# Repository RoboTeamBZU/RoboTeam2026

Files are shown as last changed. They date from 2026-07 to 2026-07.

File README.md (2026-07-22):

<div align="center">

# 🤖 RoboTeamBZU — WRO Future Engineers 2026

### Self-driving model car · LiDAR + Gyro + Encoder · Raspberry Pi 4

**Team:** RoboTeamBZU · Birzeit University · 🇵🇸 Palestine
**Members:** Bashar Ibrahim · Jinan Yousef · Basmala Assi

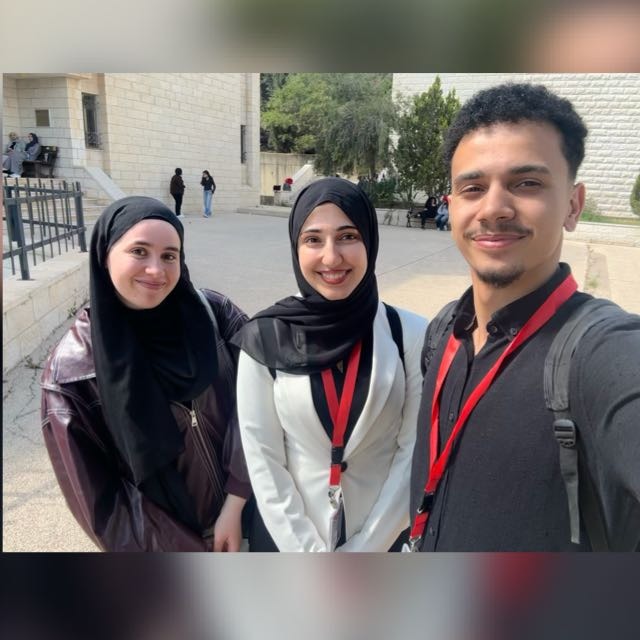
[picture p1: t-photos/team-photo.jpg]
RoboTeamBZU










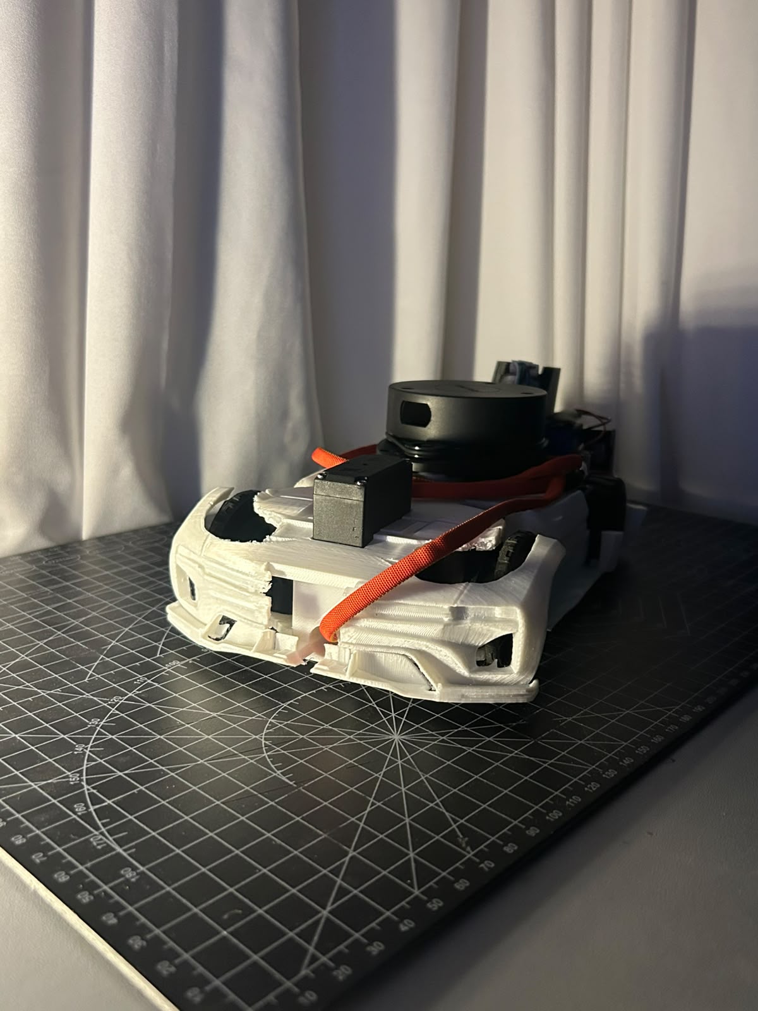
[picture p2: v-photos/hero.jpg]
RoboTeamBZU vehicle


</div>

---

## 🚗 What is this?

A small **autonomous car** that drives itself around the WRO Future Engineers track. It has **no remote control** — it senses the walls, keeps itself centered, turns at each corner, counts its laps, and stops on its own.

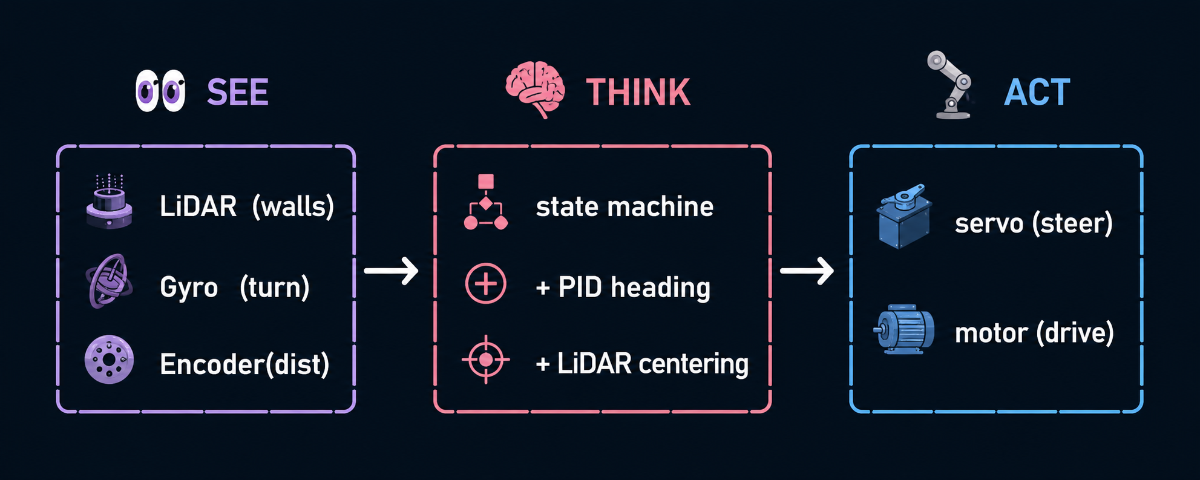
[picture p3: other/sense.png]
description


### 📸 The vehicle

| Front | Side | Top | Bottom |
|:---:|:---:|:---:|:---:|
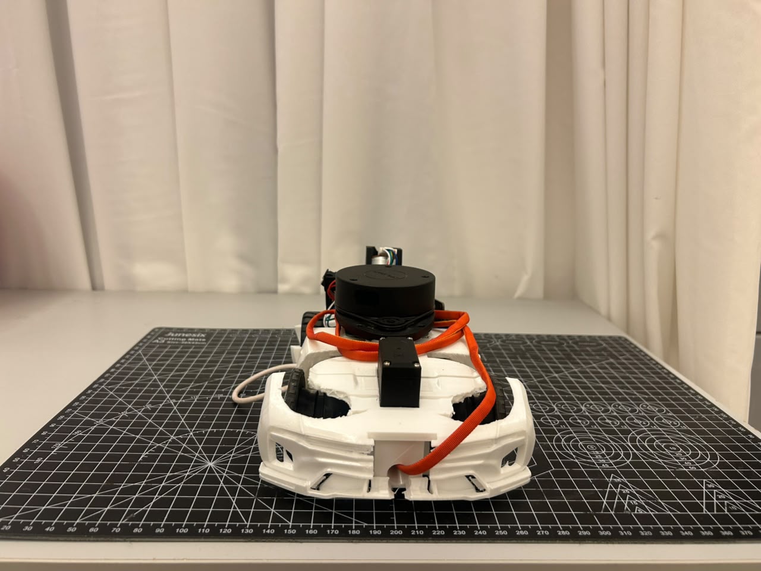
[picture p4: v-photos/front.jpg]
front
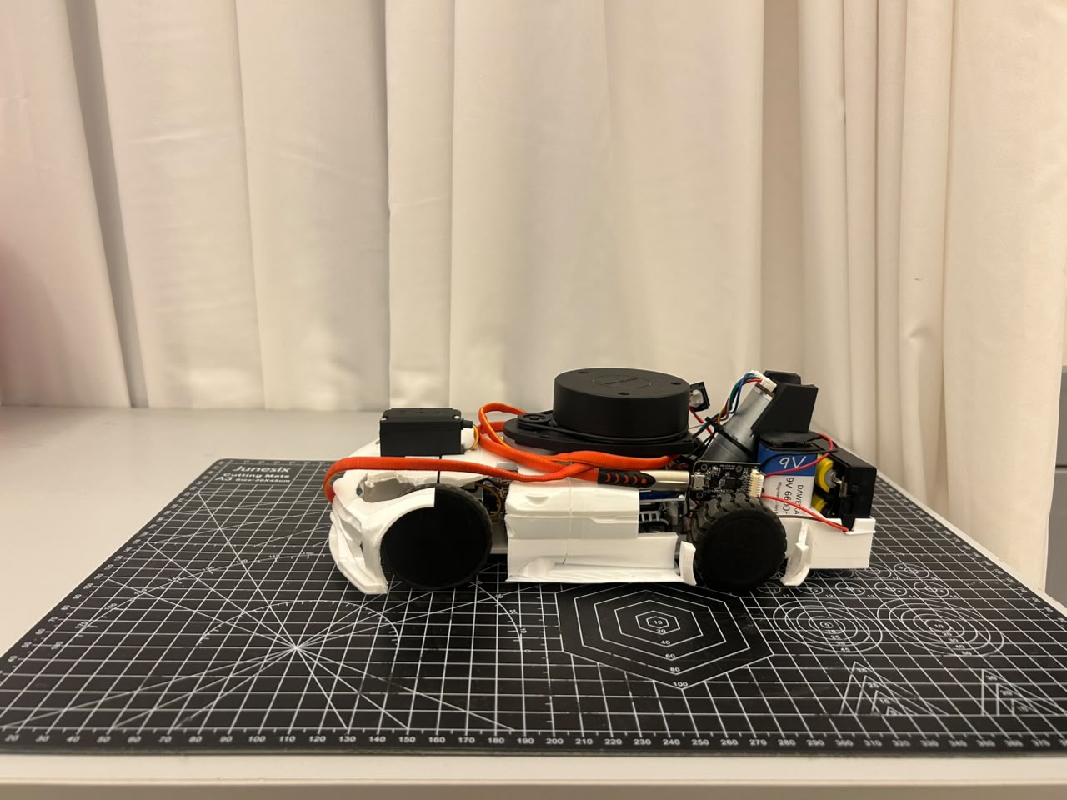
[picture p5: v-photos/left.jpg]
left
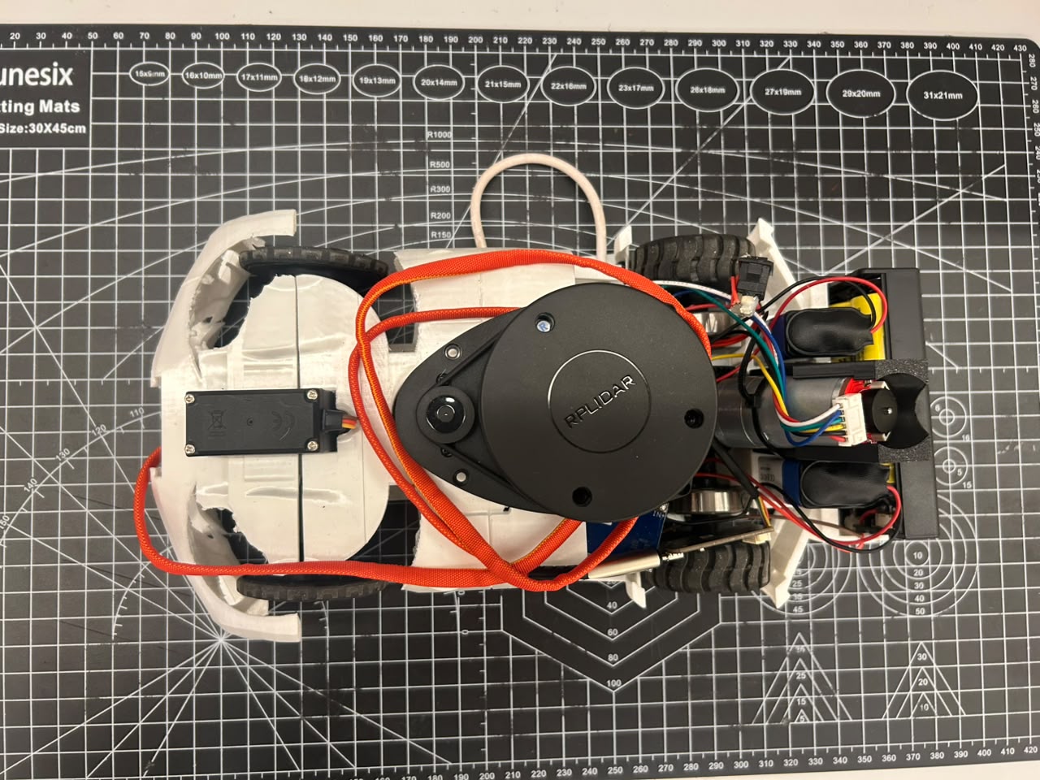
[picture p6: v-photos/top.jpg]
top
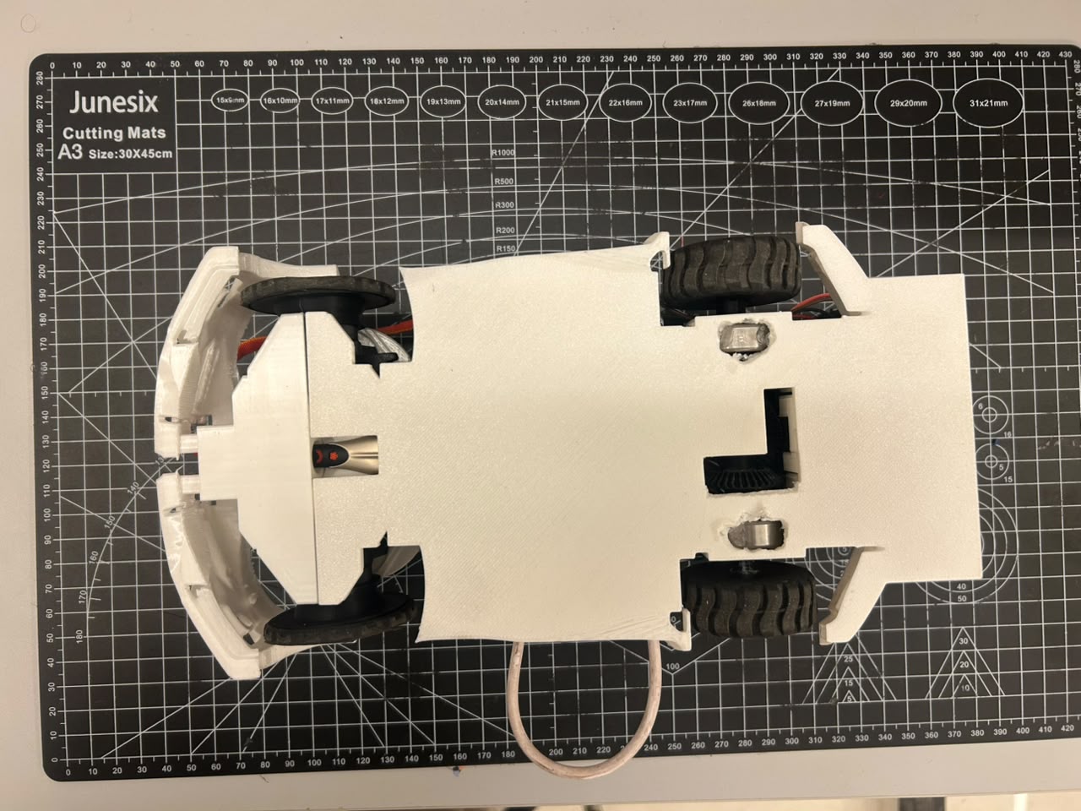
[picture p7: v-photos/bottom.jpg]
bottom
|  |  |  |  |

<sub>All six required angles are in [`/v-photos`](./v-photos).</sub>

---

## ⭐ Highlights

| | |
|---|---|
| 🧭 **Gyro-guided** | Heading held by a PID loop on the MPU6050 gyro |
| 📡 **LiDAR-centered** | RPLidar keeps the car in the middle of the lane and spots corners |
| 📏 **Dead reckoning** | Encoder + gyro track position with **no GPS** |
| 🔌 **Brownout-proof power** | 3 isolated battery sources + single star ground |
| 🖥️ **Live map** | Streams a real-time 2D/2.5D map + telemetry to a PC over Wi-Fi |
| 🔁 **Fully autonomous** | Drives with **zero** network — telemetry is optional |

---

## 🧩 How it works (30-second version)

```mermaid
flowchart LR
    L[📡 LiDAR] -->|front / left / right| C
    G[🧭 Gyro] -->|heading| C
    E[📏 Encoder] -->|distance| C
    C{🧠 State machine} -->|straight?| PID[PID + centering]
    C -->|corner?| TURN[90° turn profile]
    PID --> STEER[🦿 Servo]
    TURN --> STEER
    C --> MOTOR[⚙️ Drive motor]
    C -.optional.-> MAP[🖥️ PC live map]
```

1. **Go straight** — the gyro holds a fixed heading; the LiDAR nudges left/right to stay centered.
2. **See a wall ahead** (< 600 mm, confirmed 3×) — turn 90° toward the open side.
3. **Repeat** for **3 laps** (1080° total), then stop.
4. The turn direction (CW/CCW) is **auto-detected** at the first corner, because WRO randomizes it.

Full detail → [Software Architecture](./docs/Software-Architecture.md).

---

## 🛠️ The build at a glance

```
            ┌─────────────────────────────┐
   TOP DECK │  🍓 Pi 4   📡 LiDAR   🧭 IMU │   ← clear 360° LiDAR sweep
            └───────────────┬─────────────┘
                            │ 4× standoffs (rigid)
            ┌───────────────┴─────────────┐
   LOW DECK │ 🦿 servo   ⚙️ motor+encoder  │   ← heavy batteries kept low
            │        🔋🔋🔋 power          │
            └─────────────────────────────┘
             front (steered)      rear (driven)
```

| Subsystem | Choice | Why |
|---|---|---|
| **Drive** | 1× brushed DC motor, rear axle, DRV8833 | simple, car-like; kick-pulse launch fixes stall |
| **Steering** | servo + Ackermann, ±60° | predictable turn radius, decoupled from drive |
| **Heading** | MPU6050 gyro (Z axis) | smooth, high-rate, independent of walls |
| **Distance** | rotary encoder (205 counts/rev) | measured + tape-checked odometry |
| **Ranging** | RPLidar A1M8 | 360° walls; centering + corner detection |
| **Compute** | Raspberry Pi 4 | runs all flight code in Python |
| **Power** | 3 isolated sources, star ground | kills the brownouts a shared battery caused |

Deep dives → [Mechanical Design](./docs/Mechanical-Design.md) · [Power & Sensor Architecture](./docs/Power-and-Sensor-Architecture.md)

### 🔌 Wiring

| Schematic | Wiring diagram |
|:---:|:---:|
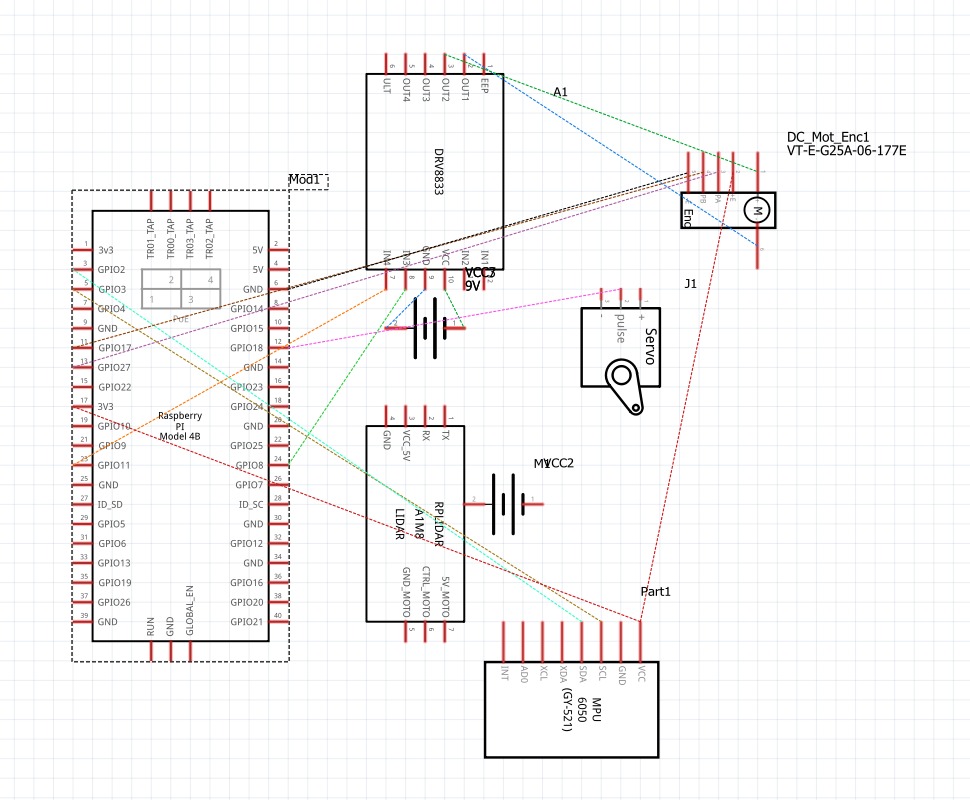
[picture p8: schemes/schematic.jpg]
schematic
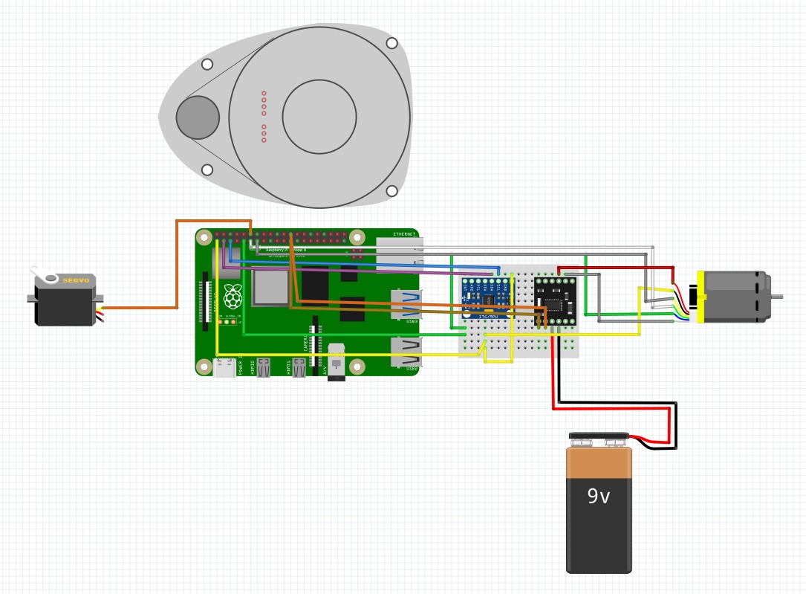
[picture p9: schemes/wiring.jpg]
wiring
|  |  |

<sub>Full pin map: [`other/pinout.md`](./other/pinout.md) · architecture notes: [`/schemes`](./schemes)</sub>

---

## 📂 Repository map

```
RoboTeam2026/
├── 📄 README.md                ← you are here
├── 📁 docs/                    ← the four engineering write-ups
│   ├── Mechanical-Design.md            (🔧 rubric 1)
│   ├── Power-and-Sensor-Architecture.md (⚡ rubric 2)
│   ├── Software-Architecture.md        (💻 rubric 3)
│   ├── Systems-Engineering.md          (🧠 rubric 4)
│   └── Build-and-Setup.md              (🛠️ how to reproduce)
├── 📁 src/                     ← all Python code
│   ├── wro_open.py             (Open Challenge autonomy)
│   ├── robot_mapper.py         (odometry + LiDAR mapping)
│   ├── map_viewer*.py          (PC live map / telemetry)
│   └── tests/                  (per-module bring-up scripts)
├── 📁 engineering-journal/     ← V1 → V2 → V3 → Final story
├── 📁 models/                  ← 3D-printable STL parts
├── 📁 schemes/                 ← wiring diagram
├── 📁 other/                   ← BOM, pinout, test procedure
├── 📁 v-photos/                ← 6 vehicle photos
├── 📁 t-photos/                ← team photos
└── 📁 video/                   ← performance video links
```

---

## 🚀 Quick start

**On the Raspberry Pi (autonomous run):**
```bash
sudo pigpiod                       # hardware-PWM daemon (jitter-free servo)
python3 src/wro_open.py            # Open Challenge — ENTER to arm, CTRL+C to stop
python3 src/grid_goto.py           # Obstacle Challenge — A* map navigation
```

**On a PC (optional live map — start this first):**
```bash
pip install numpy matplotlib pyvista
python3 src/map_viewer_pro.py      # telemetry HUD + 2.5D map
```

Full setup, dependencies, and troubleshooting → [Build & Setup](./docs/Build-and-Setup.md).

---

## 🎯 The two challenges

| Challenge | What the car must do | How | Status |
|---|---|---|---|
| 🟢 **Open Challenge** | 3 laps of a walled track, staying centered | reactive state machine: gyro PID + LiDAR centering | ✅ [`src/wro_open.py`](./src/wro_open.py) |
| 🟠 **Obstacle Challenge** | detect red/green signs, pass on the correct side, park | **live map + A\*** planner + camera color + "virtual walls" | ✅ [`src/grid_goto.py`](./src/grid_goto.py) |

**Two different brains for two problems.** The Open Challenge is *reactive* (follow the walls). The Obstacle Challenge is *deliberative*: the car builds a 50 mm occupancy grid, treats each traffic sign as a one-sided "virtual wall," and runs **A\* pathfinding** to a goal — re-planning several times a second as it discovers the track.

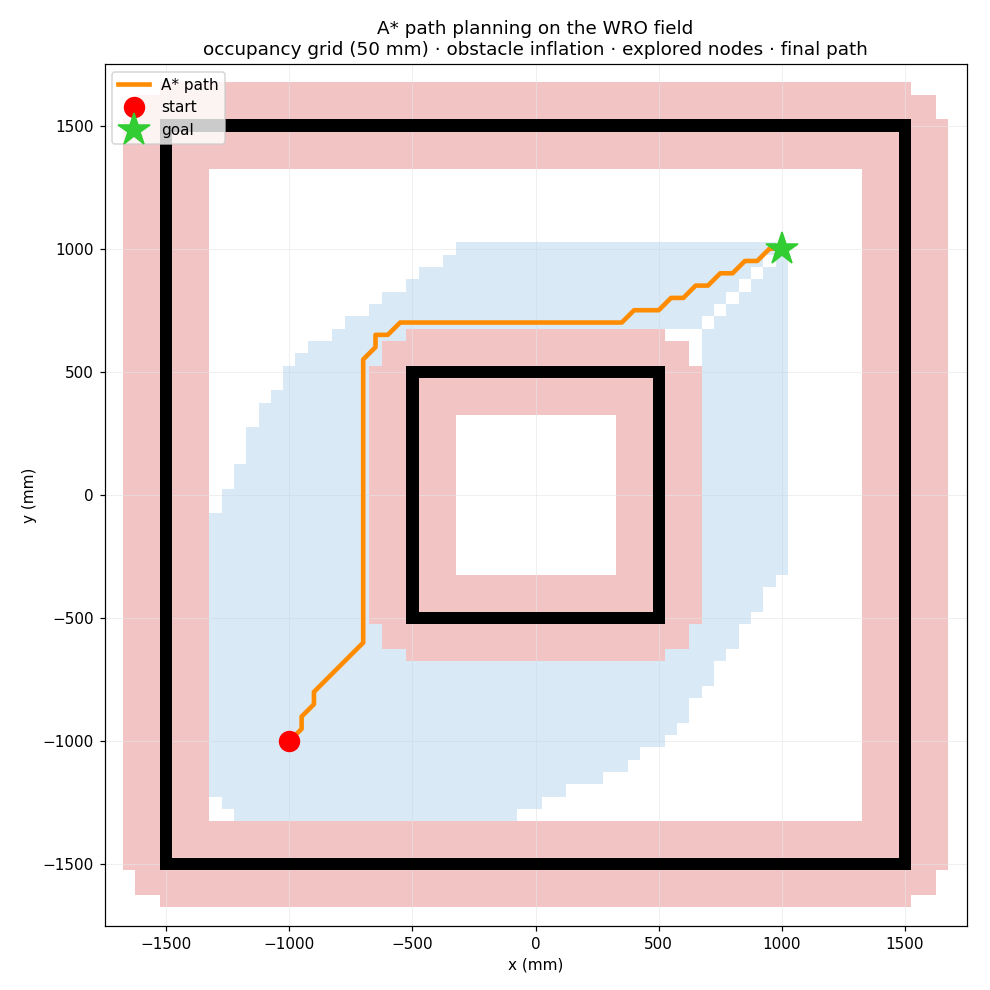
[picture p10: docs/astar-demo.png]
A* path planning on the WRO field


<sub>A\* routing the car around the inner wall — black = walls, pink = safety margin, blue = cells the search explored, orange = chosen path. Full write-up → [Software Architecture §6](./docs/Software-Architecture.md#6-obstacle-challenge-strategy--srcgrid_gotopy).</sub>

---

## 🧪 Engineering approach

We built the car in **four iterations**, each one a full *design → build → test → learn* loop:

```
V1 ──────► V2 ──────► V3 ──────► FINAL
baseline   clean       steady      repeatable
car        sensing     control     3-lap runs
```

- **V1** — car drives under gyro PID, but wanders and stalls.
- **V2** — LiDAR moved up + power split → clean scans, no brownouts.
- **V3** — hardware-PWM servo + kick pulse → no jitter, reliable launch.
- **Final** — start-line recalibration, centering smoothing, wind-up fix → consistent runs.

Read the full story → [Engineering Journal](./engineering-journal) · Trade-offs & risk analysis → [Systems Engineering](./docs/Systems-Engineering.md)

---

## 📚 Documentation index

| Doc | Covers | Rubric |
|---|---|---|
| [🔧 Mechanical Design](./docs/Mechanical-Design.md) | chassis, drive, steering, torque/speed | 1 |
| [⚡ Power & Sensor Architecture](./docs/Power-and-Sensor-Architecture.md) | power budget, wiring, sensors, calibration | 2 |
| [💻 Software Architecture](./docs/Software-Architecture.md) | state machine, PID, obstacle strategy | 3 |
| [🧠 Systems Engineering](./docs/Systems-Engineering.md) | interactions, trade-offs, iteration, risk | 4 |
| [🛠️ Build & Setup](./docs/Build-and-Setup.md) | reproduce & run the vehicle | 5 |
| [🧾 BOM](./other/BOM.md) · [🔌 Pinout](./other/pinout.md) · [✅ Test Procedure](./other/test-procedure.md) | parts, pins, validation | 5 |

---

<div align="center">

**RoboTeamBZU · Birzeit University · 🇵🇸 Palestine**
Bashar Ibrahim · Jinan Yousef · Basmala Assi

Built with 🍓 Raspberry Pi, 📡 LiDAR, and a lot of 🔁 iteration.

</div>

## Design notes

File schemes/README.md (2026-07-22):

Electromechanical diagrams
====

Diagram images in this folder (embedded in the main README):
- `schematic.jpg` — pin/connection schematic (Pi ↔ DRV8833, MPU6050, RPLidar, servo, encoder)
- `wiring.jpg` — Fritzing wiring diagram

schematic
wiring

Summary of the architecture:

**Power (three isolated sources, one star ground):**
- 9 V pack #1 → switch → DRV8833 VM (drive motor only)
- 9 V pack #2 → XL4015 buck (5.0 V) → steering servo VCC
- 2S Li-ion (7.4 V) → buck converter (5.1 V) → Raspberry Pi USB-C
- RPLidar A1M8: powered and read over a single USB connection to the Pi
- All grounds joined at one star point; the Pi connects to it with a single reference wire (Pin 9). Servo return current is routed to its own converter's ground, never through the Pi.

**Signal connections (Pi GPIO):**

| Pi pin | GPIO | Connects to |
|---|---|---|
| 1 | 3V3 | Encoder VCC, MPU6050 VCC |
| 3 | GPIO2 (SDA) | MPU6050 SDA |
| 5 | GPIO3 (SCL) | MPU6050 SCL |
| 9 | GND | Star ground (reference) |
| 11 | GPIO17 | Encoder A |
| 12 | GPIO18 | Servo signal (hardware PWM via pigpio) |
| 13 | GPIO27 | Encoder B |
| 16 | GPIO23 | DRV8833 IN1 |
| 18 | GPIO24 | DRV8833 IN2 |

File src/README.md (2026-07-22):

Control software
====

All code runs on the vehicle's Raspberry Pi 4 except the `map_viewer*` scripts, which run on a PC on the same Wi-Fi network and receive telemetry over UDP.

| File | Runs on | Purpose |
|---|---|---|
| `wro_open.py` | Pi | Open Challenge: state-machine navigation (gyro PID + LiDAR centering/corners) with built-in telemetry streaming |
| `grid_goto.py` | Pi | Obstacle Challenge: live 50 mm occupancy grid + A* planner + Pi-Camera sign detection + virtual-wall avoidance (streams to `grid_viewer.py`) |
| `robot_mapper.py` | Pi | Standalone odometry + LiDAR world-mapping streamer (mapping tests without driving logic) |
| `map_viewer.py` | PC | 2D top-down live map (matplotlib) |
| `map_viewer_3d.py` | PC | 2.5D live map (pyvista), walls extruded to real 100 mm height |
| `map_viewer_pro.py` | PC | 2.5D map + full telemetry HUD, chase camera, textured floor |
| `grid_viewer.py` | PC | Live occupancy-grid viewer for `grid_goto.py`: black cells, A* path/corridor, pillars, virtual walls, clickable coordinates |
| `sim/field_astar_demo.py` | PC | Offline A* illustration on a simulated WRO field (renders `docs/astar-demo.png`) |
| `tests/` | Pi | Component bring-up and calibration scripts, one per hardware module |

Dependencies (Pi): `adafruit-circuitpython-mpu6050`, `rplidar-roboticia`, `gpiozero`, pigpio built from source with `pigpiod` running. Obstacle Challenge (`grid_goto.py`) additionally uses `picamera2`, `opencv-python`, and `numpy` for the camera colour pipeline.
Dependencies (PC viewers): `numpy`, `matplotlib`, `pyvista`.

Calibrated constants used throughout: encoder 205 counts/rev (0.674 mm/count, 44 mm wheels); LiDAR direction windows remapped for a 180°-rotated mount; `GYRO_DIRECTION=-1`, `SERVO_DIRECTION=+1` (positive = left).

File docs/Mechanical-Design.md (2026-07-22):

# 🔧 Mechanical Design — Mobility & Chassis

> **Rubric criterion 1 — Mobility & Mechanical Design.** This document explains *what* the vehicle is built from, *why* each mechanical choice was made, and *how* those choices were validated through testing and iteration.

---

## 1. Overview

The vehicle is a **single-motor, front-steering (Ackermann-style) autonomous car** built on a rigid two-deck chassis. One brushed DC motor drives the rear axle; a servo steers the front wheels. This is the classic "car-like" layout the WRO Future Engineers rules assume, and it keeps the mechanics simple so engineering effort could go into sensing and control.

| Property | Value |
|---|---|
| Drive type | Rear-wheel drive, 1 × brushed DC motor |
| Steering | Front, servo-actuated Ackermann linkage |
| Wheel diameter | 44 mm |
| Track / wheelbase | See CAD in [`/models`](../models) |
| Turning basis | Gyro-closed-loop, ±60° servo range |
| Chassis | Two-deck (drivetrain below, electronics above) |
| Compute | Raspberry Pi 4 |

📷 Vehicle photos: [`/v-photos`](../v-photos) · CAD/STL: [`/models`](../models)

---

## 2. Chassis structure

```
        ┌─────────────────────────────┐   ← Upper deck: Pi, IMU, LiDAR,
        │   [Pi]  [LiDAR]   [IMU]      │     power distribution
        │                             │
        └───────────┬─────────────────┘
                    │ standoffs (4×)
        ┌───────────┴─────────────────┐   ← Lower deck: motor, driver,
   ┌──┐ │ [servo]        [motor+enc]  │ ┌──┐  battery packs, servo
   │  │ │      Ackermann     ▐▐       │ │  │
   └──┘ └─────────────────────────────┘ └──┘
   front                                 rear
 (steered)                            (driven)
```

**Why two decks?** Separating the drivetrain (lower) from the sensing/compute stack (upper) does three things:

1. **Keeps the LiDAR plane clear.** The RPLidar A1M8 needs an unobstructed 360° sweep. Mounting it on the top deck above the tallest components guarantees a clean scan of the field walls.
2. **Shortens and isolates wiring.** High-current motor wiring stays on the lower deck; low-level signal wiring (I²C, encoder, servo PWM) stays up top, reducing noise coupling.
3. **Lowers the center of mass** by keeping the heavy battery packs low, which improves stability during hard cornering.

The two decks are joined by four metal standoffs, giving a torsionally rigid frame — important because chassis flex would change the LiDAR-to-wall geometry mid-run and corrupt the wall-centering trim.

---

## 3. Drivetrain — motor & speed/torque reasoning

A single **brushed DC gearmotor** drives the rear axle through the wheels (44 mm diameter). Drive power comes from a dedicated 9 V pack through a **DRV8833** H-bridge driver.

### Speed vs. torque trade-off

The WRO field is a small arena; the vehicle needs **enough top speed to be competitive but enough low-end torque to launch cleanly from a standstill** and to hold speed through gyro-corrected steering corrections. Our reasoning:

| Requirement | Consequence for gearing |
|---|---|
| Fast, clean laps | Favor higher RPM |
| Reliable start from rest | Need standstill torque |
| Predictable control loop | Speed must be repeatable, not twitchy |

We run the motor at **80 % duty on straights** (`SPEED_STRAIGHT = 0.8`) and **55 % in turns** (`SPEED_TURN = 0.55`) — slowing for corners keeps the gyro turn profile repeatable and prevents understeer.

### The standstill-torque problem (and fix)

Early testing (see [engineering journal](../engineering-journal)) showed the motor could **stall at low duty when starting from rest** — not enough torque to overcome static friction. We solved it two ways:

1. **Mechanically** — reduced drivetrain friction and confirmed free-spinning wheels.
2. **In software** — a **kick pulse**: the driver briefly commands full power (`KICK_SPEED = 1.0` for `KICK_TIME = 0.15 s`) whenever the motor starts from rest, then drops to the commanded duty. This is retained as a safety margin. See `motor()` in [`src/wro_open.py`](../src/wro_open.py).

---

## 4. Steering — Ackermann servo linkage

The front wheels are steered by a single **servo** driving an Ackermann-style linkage. Key parameters (from [`src/wro_open.py`](../src/wro_open.py)):

| Parameter | Value | Meaning |
|---|---|---|
| `SERVO_MAX` | 60° | Mechanical steering limit |
| `SERVO_DIRECTION` | +1 | Positive command = steer **left** |
| `TURN_FULL_LOCK` | 55° | Angle held during a 90° corner |
| `TURN_RELEASE_DEG` | 25° | Ease off lock this close to target heading |

**Why a servo (not differential/skid steering)?** A steered front axle matches the car-like geometry of the challenge, produces a **predictable turn radius**, and lets us decouple *steering* from *drive* — the drive motor holds speed while the servo alone corrects heading. This makes the control problem far simpler than balancing two drive motors.

### Servo jitter fix
The servo jittered on software PWM. We moved it to the Pi's **hardware PWM via `pigpio`** (daemon `pigpiod`, built from source), which eliminated the jitter and gave a rock-steady steering signal. Documented in [`other/test-procedure.md`](../other/test-procedure.md).

---

## 5. Sensor mounting (mechanical)

| Sensor | Mount location | Mechanical reasoning |
|---|---|---|
| **RPLidar A1M8** | Top deck, highest point | Clear 360° sweep of walls; mounted **180° rotated** — compensated in software (`LIDAR_MOUNT_OFFSET = 180`) rather than re-machining the mount |
| **MPU6050 (IMU)** | Top deck, near center of rotation | Placing it close to the vehicle's yaw axis minimizes translational acceleration coupling into the gyro reading |
| **Rotary encoder** | On the drive axle | Direct odometry from wheel rotation; 205 counts/rev measured experimentally |

The LiDAR's 180° rotation is a good example of **choosing the cheaper fix**: instead of building a new bracket, we remapped the angle windows in code (front `170–190°`, left `80–100°`, right `260–280°`).

---

## 6. Design iterations that changed the mechanics

| Version | Mechanical change | Why |
|---|---|---|
| V1 | Baseline single-motor + servo chassis | Establish a working car-like platform |
| V2 | Raised & isolated LiDAR to top deck | Earlier low mount caught part of its own chassis in the sweep |
| V3 | Added kick-pulse-friendly drivetrain, hardware-PWM servo mount | Fix standstill stall + steering jitter |
| Final | Rigid two-deck standoff frame, IMU relocated near yaw axis | Reduce flex + cleaner heading signal |

Full narrative with photos: [engineering journal](../engineering-journal).

---

## 7. Reproducibility

- **CAD / STL** files: [`/models`](../models)
- **Vehicle photos** (all six angles required by WRO): [`/v-photos`](../v-photos)
- **Calibrated constants** (wheel diameter, counts/rev, servo range): [`other/pinout.md`](../other/pinout.md)
- **Bill of materials**: [`other/BOM.md`](../other/BOM.md)

Anyone with the CAD, the BOM, and the calibrated constants above can reproduce this chassis.

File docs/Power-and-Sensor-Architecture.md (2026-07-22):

# ⚡ Power & Sensor Architecture

> **Rubric criterion 2 — Power & Sensor Architecture.** This document covers the power system layout, the power budget, wiring, and every sensor: what it is, where it is placed, why, and how it is calibrated. The full wiring diagram lives in [`/schemes`](../schemes) and the exact pin map in [`other/pinout.md`](../other/pinout.md).

---

## 1. Design principle: three isolated sources, one star ground

The single most important power decision was to **split the vehicle onto three isolated power sources** and join them at a **single star ground**. Motors and servos create large, noisy current spikes; the Raspberry Pi and the I²C sensors are sensitive to voltage sag and ground bounce. Sharing one battery caused **brownouts and I²C errors** in early testing. Isolating the loads fixed it.

```
   ┌──────────────┐
   │ 9V pack #1   │──[switch]──► DRV8833 VM ──► DRIVE MOTOR
   └──────────────┘                              (noisy, high current)

   ┌──────────────┐
   │ 9V pack #2   │──► XL4015 buck (5.0V) ──► STEERING SERVO VCC
   └──────────────┘                              (spiky, inductive)

   ┌──────────────┐
   │ 2S 18650     │──► buck (5.1V) ──► USB-C ──► RASPBERRY PI 4
   │ Li-ion 7.4V  │                              (sensitive logic)
   └──────────────┘

   ┌──────────────┐
   │ RPLidar A1M8 │──── single USB cable (power + data) ──► Pi
   └──────────────┘

   ── ALL GROUNDS ──► ONE STAR POINT ──► single ref wire ──► Pi Pin 9
```

**Key rule:** the servo's return current is routed to *its own* converter ground, **never through the Pi**. This keeps servo current spikes out of the logic ground.

---

## 2. Power budget

| Rail | Source | Regulator | Feeds | Approx. draw |
|---|---|---|---|---|
| Motor VM | 9 V pack #1 | none (direct to DRV8833) | Drive motor | High, spiky (stall inrush) |
| Servo 5.0 V | 9 V pack #2 | XL4015 buck | Steering servo | Spiky under load |
| Pi 5.1 V | 2S 18650 (7.4 V) | buck → USB-C | Pi 4 + IMU + encoder | ~0.6–1.2 A continuous |
| LiDAR 5 V | Pi USB | (from Pi supply) | RPLidar A1M8 motor + sensor | ~0.3–0.5 A |
| 3.3 V logic | Pi onboard | Pi regulator | MPU6050, encoder | Low |

> ⚠️ **Why the Pi gets its own Li-ion pack:** the Pi + LiDAR is the largest *sustained* draw and the least tolerant of voltage sag. A dedicated 2S 18650 with a buck to 5.1 V keeps it above the brownout threshold even while the motor stalls.

---

## 3. Wiring / signal connections

Signal wiring from the Pi GPIO header (full table in [`other/pinout.md`](../other/pinout.md)):

| Pi pin | GPIO | Connects to |
|---|---|---|
| 1 | 3V3 | Encoder VCC, MPU6050 VCC |
| 3 | GPIO2 (SDA) | MPU6050 SDA |
| 5 | GPIO3 (SCL) | MPU6050 SCL |
| 9 | GND | **Star ground reference** |
| 11 | GPIO17 | Encoder A |
| 12 | GPIO18 | Servo signal (**hardware PWM** via pigpio) |
| 13 | GPIO27 | Encoder B |
| 16 | GPIO23 | DRV8833 IN1 |
| 18 | GPIO24 | DRV8833 IN2 |

Full Fritzing wiring diagram: [`/schemes`](../schemes).

---

## 4. Sensor suite

The vehicle localizes and navigates with three sensors. There is no GPS or external reference — everything is **onboard dead reckoning + LiDAR ranging**.

### 4.1 MPU6050 — IMU / gyro (heading)

| Property | Value |
|---|---|
| Interface | I²C (SDA GPIO2, SCL GPIO3) |
| Used axis | Z-axis gyro (yaw rate) |
| Placement | Top deck, near the vehicle's center of rotation |
| Role | Primary **heading** source — integrated to drive the steering PID |

**Placement reasoning:** mounting the IMU near the yaw axis minimizes translational acceleration bleeding into the gyro signal, giving a cleaner heading integral.

**Calibration & failure handling:**
- **Bias calibration at startup:** 300 samples of Z-gyro are averaged with the robot held still to compute `gyro_offset`, which is subtracted from every reading (`calibrate_gyro()`).
- **Thermal drift:** we measured ~1°/3 s drift traced to thermal bias. Mitigation: **re-calibrate at the start line after a 60 s warm-up**.
- **Deadzone:** small rates below `GYRO_DEADZONE` are zeroed so slow sensor noise doesn't accumulate into false heading, while real veers still register.

### 4.2 Rotary encoder — odometry (distance)

| Property | Value |
|---|---|
| Interface | Quadrature A/B (GPIO17, GPIO27) |
| Counts/rev | **205 (measured experimentally)** |
| Wheel diameter | 44 mm |
| Derived | `MM_PER_COUNT = π·44 / 205 ≈ 0.674 mm` |
| Direction | `ENCODER_DIRECTION = -1` |

**Calibration:** counts/rev were **measured**, not assumed, then **cross-checked** by pushing the robot exactly 500 mm along a tape measure and confirming the odometry read ~500 mm (`test_distance.py`).

### 4.3 RPLidar A1M8 — ranging (walls & corners)

| Property | Value |
|---|---|
| Interface | USB (`/dev/ttyUSB0` @ 115200), power + data on one cable |
| Placement | Highest point on the top deck (clear 360° sweep) |
| Mount orientation | **180° rotated** — compensated in software |
| Role | Wall-centering trim + front-wall corner trigger |

**Direction windows (robot frame, after the 180° remap):**

| Window | Angles | Used for |
|---|---|---|
| Front | 170–190° | Corner trigger (`front < 600 mm`) |
| Left | 80–100° | Centering + open-corridor detection |
| Right | 260–280° | Centering + open-corridor detection |
| Back | 350–360° / 0–10° | (available) |

**Calibration & failure handling:**
- Four-direction wall distances validated against a tape measure (`test_lidar_pi.py`).
- **Stale-stream bug fix:** a `stop()` + `reset()` is issued at startup after we discovered stale-descriptor errors on reconnect.
- Points with `quality == 0` or out of `MAX_DIST` (3000 mm) are discarded before use.

### 4.4 Raspberry Pi Camera — traffic-sign color (Obstacle Challenge)

| Property | Value |
|---|---|
| Part | 5 MP 175° fisheye CSI camera (OV5647, 1.7 mm lens) |
| Interface | CSI ribbon to the Pi |
| Placement | Front, facing forward, above the bumper |
| Role | Reads **red vs. green** traffic-sign pillars |
| Power | From the Pi (no separate rail) |

**How it's used:** LiDAR finds a pillar's *bearing*; the camera samples the HSV color at that bearing to decide the pass side. Red is matched with two hue ranges (hue wraps at 0/180°); a minimum pixel count rejects ambiguous frames. Details in [Software Architecture §6.3](./Software-Architecture.md#63-detecting-the-signs-sensor-fusion-lidar--camera). The Open Challenge does not use the camera.

---

## 5. Sensor fusion summary

```
 ENCODER ──(distance)──┐
                       ├──► DEAD-RECKONED POSE (x, y) ──► live map + odometry
 GYRO ─────(heading)───┘
                       └──► heading feeds STEERING PID (straights)
                                          + TURN profile (corners)

 LiDAR ──(front)──► corner trigger
       ──(left/right)──► wall-centering trim  +  turn-direction detection
```

Heading comes **only** from the gyro; distance comes **only** from the encoder; LiDAR never feeds the pose estimate directly — it corrects *where in the lane* the car sits and *when* to turn. This clean separation is what makes the failure modes easy to reason about (see [Systems Engineering](./Systems-Engineering.md)).

---

## 6. Reproducibility

- Wiring diagram: [`/schemes`](../schemes)
- Exact pinout + calibrated constants: [`other/pinout.md`](../other/pinout.md)
- Per-sensor bring-up scripts: [`src/tests/`](../src/tests)
- Component test log: [`other/test-procedure.md`](../other/test-procedure.md)
- Parts & sourcing: [`other/BOM.md`](../other/BOM.md)

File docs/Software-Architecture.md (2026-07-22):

# 💻 Software Architecture & Obstacle Strategy

> **Rubric criterion 3 — Software Architecture & Obstacle Strategy.** This document explains the code structure, the state machine, the control algorithms (PID, dead reckoning, LiDAR logic), how edge cases are handled, and how the software was tuned and validated. Source lives in [`/src`](../src).

---

## 1. Code map

All flight code runs on the **Raspberry Pi 4**; the `map_viewer*` scripts run on a **PC** on the same Wi-Fi and receive telemetry over UDP.

| File | Runs on | Purpose |
|---|---|---|
| [`src/wro_open.py`](../src/wro_open.py) | Pi | **Open Challenge** — state-machine navigation (gyro PID + LiDAR centering/corners) with telemetry streaming |
| [`src/grid_goto.py`](../src/grid_goto.py) | Pi | **Obstacle Challenge** — live occupancy grid + A\* planner + camera sign detection + virtual-wall avoidance |
| [`src/robot_mapper.py`](../src/robot_mapper.py) | Pi | Standalone odometry + LiDAR world-mapping streamer (mapping tests without driving logic) |
| [`src/map_viewer.py`](../src/map_viewer.py) | PC | 2D top-down live map (matplotlib) |
| [`src/map_viewer_3d.py`](../src/map_viewer_3d.py) | PC | 2.5D live map (pyvista), walls extruded to real 100 mm height |
| [`src/map_viewer_pro.py`](../src/map_viewer_pro.py) | PC | 2.5D map + full telemetry HUD, chase camera, textured floor |
| [`src/grid_viewer.py`](../src/grid_viewer.py) | PC | Live **occupancy-grid** viewer for the Obstacle Challenge: black cells, A\* path/corridor, pillars, virtual walls, robot arrow (click a cell to read its coordinates) |
| [`src/sim/field_astar_demo.py`](../src/sim/field_astar_demo.py) | PC | Offline A\* illustration on a simulated WRO field (generates the figure below) |
| [`src/tests/`](../src/tests) | Pi | Per-module bring-up & calibration scripts |

**Design philosophy:** small, single-responsibility modules. Sensing, pose estimation, control, and telemetry are separate functions so any one can be tested or retuned in isolation. That modularity is why each hardware module has its own test script (see [`other/test-procedure.md`](../other/test-procedure.md)).

---

## 2. The Open Challenge state machine

The Open Challenge is three laps of a walled track (no obstacles). The vehicle must stay centered, take corners, and stop after **3 laps = 1080° of cumulative heading**.

```mermaid
stateDiagram-v2
    [*] --> ARMED: press ENTER
    ARMED --> STRAIGHT: state zeroed, 1s corner-blind
    STRAIGHT --> STRAIGHT: gyro PID holds heading\nLiDAR trims to lane center
    STRAIGHT --> TURNING: front wall < 600mm\n(confirmed 3 scans)
    TURNING --> STRAIGHT: heading within 4° of target\n(+0.4s corner-blind)
    STRAIGHT --> FINISHED: |heading| >= 1080° - 15°
    FINISHED --> [*]: motor stop, servo center
```

| State | What it does |
|---|---|
| **ARMED** | On ENTER, all state is zeroed (heading, encoder, PID terms) and a 1 s "corner-blind" window prevents a false corner at the start line. |
| **STRAIGHT** | Gyro PID holds the snapped target heading (0/90/180/270…). LiDAR left/right distances trim the target to keep the car centered in the lane. Watches the front window for a corner. |
| **TURNING** | Full-lock steering toward `snapped + 90°·turn_dir`, easing off as it approaches. Drive slows to `SPEED_TURN`. |
| **FINISHED** | After 1080° cumulative heading, stop motor and center steering. |

**Turn direction is auto-detected** at the first corner (WRO randomizes CW/CCW): whichever side reads as the open corridor (`> 900 mm`) sets `turn_dir` for the whole run.

---

## 3. Control algorithms

### 3.1 Heading hold — PID on the straights
`pid_steer()` in [`wro_open.py`](../src/wro_open.py) runs a PID controller on heading error (`target − heading`):

| Gain | Value | Role |
|---|---|---|
| `KP` | 0.9 | Proportional — main corrective push |
| `KI` | 0.05 | Integral — removes steady drift (clamped ±30 to stop wind-up) |
| `KD` | 0.15 | Derivative — damps oscillation (low-pass filtered, `KD_FILTER = 0.3`) |

Integral is **reset when exiting a turn** so wind-up from the corner isn't carried into the next straight — a deliberate edge-case fix.

### 3.2 Lane centering — LiDAR trim
On straights, `smoothed_center_error(left, right)` averages the last 4 scans of `(left − right)`. Within a 30 mm deadzone the trim is zero; otherwise the target heading is nudged by up to ±6° (`CENTER_GAIN`, `CENTER_TRIM_MAX`) to steer back to the lane center. Smoothing prevents single noisy scans from jerking the wheel.

### 3.3 Corner detection & turn profile
- **Trigger:** front wall closer than `TURN_TRIGGER_DIST = 600 mm`, confirmed over `TURN_CONFIRM = 3` consecutive scans (debounce against a single bad reading).
- **Profile:** `turn_steer()` holds full lock (`55°`) until within `TURN_RELEASE_DEG = 25°` of the target, then ramps down linearly for a clean exit within `TURN_EXIT_TOL = 4°`.

### 3.4 Pose estimation — dead reckoning
`update_pose()` fuses **gyro (heading)** and **encoder (distance)** each loop:
```
heading += gyro_z * dt          # integrated yaw rate
x += Δdistance * cos(heading)   # advance along heading
y += Δdistance * sin(heading)
```
This pose drives the live map and telemetry. LiDAR points are transformed into world coordinates and streamed to the PC viewers.

---

## 4. Edge cases handled

| Edge case | Handling |
|---|---|
| False corner at start line | 1 s `START_BLIND` window after ARM |
| Double-trigger right after a turn | 0.4 s `POST_TURN_BLIND` window |
| Single noisy LiDAR scan | 3-scan confirm + 4-scan centering smoothing |
| PID wind-up through corners | integral clamped and reset on turn exit |
| Motor stall from rest | kick pulse (full power for 0.15 s) |
| Gyro thermal drift | warm-up + re-calibration at start line |
| LiDAR stale stream on reconnect | `stop()` + `reset()` at startup |
| Network hiccup | telemetry send wrapped in try/except; tracking continues |

---

## 5. Tuning & validation

Every module was validated in isolation before integration ([`other/test-procedure.md`](../other/test-procedure.md)):

1. **Servo** — sweep test; jitter fixed with hardware PWM.
2. **Gyro** (`test_gyro.py`) — verified 90°/360° physical rotations; measured drift.
3. **Motor** (`test_motor.py`) — direction + ramp; stall fix verified.
4. **Encoder** (`test_encoder.py`, `test_distance.py`) — 205 counts/rev, cross-checked at 500 mm.
5. **LiDAR** (`test_lidar_pi.py`) — four-direction distances vs. tape measure.
6. **Turning** (`test_turn.py`) — closed-loop turns to absolute headings.
7. **Mapping** — pushed-lap test: walls form closed straight lines and the trail returns to origin, validating dead reckoning **before** any autonomous run.

**Metric used to validate the map/odometry:** after a hand-pushed loop, the trail must return to the origin and walls must close into straight lines — a direct visual check that encoder + gyro drift is within tolerance.

---

## 6. Obstacle Challenge strategy — [`src/grid_goto.py`](../src/grid_goto.py)

The Obstacle Challenge replaces "follow the walls" with **"know where you are and plan a path."** Instead of a reactive state machine, the car builds a **live map** and runs an **A\* planner** to a goal cell, re-planning several times a second as the map fills in. Traffic signs (pillars) become geometry the planner must respect.

### 6.1 The big idea: occupancy grid + A\*
```mermaid
flowchart TD
    L[📡 LiDAR scan] --> G[50 mm occupancy grid\nfree / occupied / unknown]
    P[🧭 Gyro + 📏 Encoder] --> POSE[Pose x,y,h]
    POSE --> G
    CAM[📷 Pi Camera] --> PIL[Pillar color RED/GREEN]
    L --> PIL
    PIL --> VW[Virtual walls\non the forbidden side]
    G --> ASTAR{A* planner}
    VW --> ASTAR
    ASTAR --> WP[Waypoint follower\npure-pursuit steering]
    WP --> DRIVE[Servo + motor]
    ASTAR -.replan every 0.5s.-> ASTAR
```

- **The world is a grid of 50 mm cells** (`GRID_RESOLUTION_MM = 50`). The car starts at cell `(0,0)`, heading 0.
- Each LiDAR ray marks cells **free** along its length and **occupied** at its endpoint, using a confidence count (`OCC_CONFIRM = 3`) so one noisy scan can't create a phantom wall (`update_grid`, `occupied_cells`).
- **Unknown cells are treated as free** (optimistic planning): the car assumes open space and **re-plans every `REPLAN_S = 0.5 s`** as reality is revealed — this is what lets it start driving before it has seen the whole track.

#### How A\* finds the route

A* path planning on the WRO field

*The exact `astar()` from [`grid_goto.py`](../src/grid_goto.py), run offline on a simulated WRO field ([`src/sim/field_astar_demo.py`](../src/sim/field_astar_demo.py)). Black = real walls, pink = obstacle-inflation no-go zone, blue = cells A\* explored, orange = the final path.*

A\* is a best-first search that finds the **shortest collision-free path** from the robot's cell to the goal cell. For each candidate cell it keeps a score `f = g + h`:

- **`g`** — the real distance travelled from the start to that cell (straight moves cost `1.0`, diagonals `1.414`).
- **`h`** — a *heuristic* estimate of the distance still to go, here the straight-line (Euclidean) distance to the goal. Because `h` never over-estimates, A\* is guaranteed to return the shortest path.

It always expands the lowest-`f` cell next, which is why the blue "explored" region fans out *toward* the goal instead of searching everywhere — A\* is far cheaper than flooding the whole grid. Key implementation details in our version:

1. **Obstacle inflation** — every wall cell is grown by the robot's radius (`OBSTACLE_INFLATION_MM = 130 mm`, the pink band) so the *center* of the car can follow the path without a corner clipping a wall.
2. **Diagonal corner-cutting is blocked** — a diagonal move is only allowed if both orthogonal neighbours are free, so the path never squeezes through a wall's corner.
3. **Escape bubble** — the cells around the start are force-cleared so a car that starts hemmed against a wall can always plan its way out.
4. **Path simplification** — `simplify()` collapses the raw cell staircase into the fewest straight segments that stay collision-free, giving the smooth orange line the pure-pursuit follower actually drives.

In the figure the planner routes the car out of the bottom-left lane, **around the inner wall**, and into the top-right — exactly the reasoning it performs live, several times a second, as new walls and pillars appear.

### 6.2 Traffic signs → "virtual walls"
This is the core avoidance trick. A red pillar must be passed on one side, a green pillar on the other. Rather than special-casing steering, we turn each rule into **geometry the planner obeys** (`pillar_constraints`):

| Sign | Rule | What the code does |
|---|---|---|
| 🔴 **RED** | pass on the pillar's **right** | builds a **virtual wall** extending to the **left** of the approach line |
| 🟢 **GREEN** | pass on the pillar's **left** | builds a virtual wall extending to the **right** |

The virtual wall is a thin line of blocked cells on the forbidden side, plus an **L-shaped cap** forward from its tip so A\* can't sneak around the end through unknown-as-free space. The result: **A\* has exactly one legal way past each sign**, and steering falls out of the plan automatically. Passed pillars are culled (`_along(t) > -400`) so they never constrain the car again.

### 6.3 Detecting the signs (sensor fusion: LiDAR + camera)
1. **LiDAR finds candidates** (`find_pillars`): points inside a forward cone (`PILLAR_CONE_DEG = 40°`) are clustered; a cluster only counts as a pillar if it is **small** (`CLUSTER_MAX_SPAN ≤ 120 mm`) and **isolated** from the walls behind it (`isolated()` depth check). This rejects walls and corners.
2. **Camera reads the color** (`get_color`): the Pi Camera frame is converted to HSV and the region of interest **at the pillar's bearing** is sampled. Red uses two HSV ranges (the hue wraps at 0/180); the color with more pixels wins, above a `COLOR_MIN_PIXELS = 150` threshold. If no camera is present, a fallback alternates RED/GREEN for bench testing.
3. **Tracking** (`update_tracks`): detections are matched frame-to-frame in world coordinates and only promoted to a real pillar after `PILLAR_CONFIRM = 3` consistent hits — debouncing false positives before they ever affect the plan.

### 6.4 Following the plan
- **Pure-pursuit steering:** the follower aims at a **lookahead point** `LOOKAHEAD_MM = 210` along the path and steers with a proportional law (`HEAD_KP = 1.1`), interpolating between waypoints for a smooth line.
- **Closed-loop speed:** a PI controller (`SPD_KP`, `SPD_KI`) holds a target ground speed measured from pose deltas, slowing to `TARGET_MMS_TURNY = 180 mm/s` when the heading error is large and running `300 mm/s` on straights.
- **Path simplification:** `simplify()` collapses the A\* cell path into the fewest straight segments that stay collision-free, so the car drives smooth lines instead of a staircase.

### 6.5 Getting unstuck (edge cases)
| Situation | Detection | Recovery |
|---|---|---|
| Wall dead ahead | `front < EMERGENCY_STOP_MM (130)` | reverse `STUCK_REV_MM` then re-plan (`reverse_out` → recursive `goto_cell`) |
| Not moving but commanded to | `meas_mms < STALL_MMS` for `STUCK_S = 1.2 s` | reverse + re-plan |
| Motor won't launch | speed near zero | **kick pulse** (full power `0.15 s`), forward or reverse |
| Goal sits inside a wall zone | `nearest_free()` | nudge the goal to the closest free cell (`GOAL_SEARCH_R = 6`) |
| Robot starts hemmed in | — | A\* carves an escape bubble around the start cell |
| LiDAR stream dies | exception in scan thread | auto `stop()`+`reset()` and reconnect |

### 6.6 Safety & workflow details
- **Idle thread** keeps pose + map updating while the program waits at the target prompt, so the map is live and `dt` never goes stale between goals.
- **`flush_pose()`** discards odometry accumulated while idle (e.g. if the robot was handled), so stale motion never integrates into the pose.
- **Pre-start preview:** before arming, the viewer shows a raw LiDAR preview so the team can confirm the track outline; on ENTER the gyro is calibrated (600 samples, warm chip) and the real map starts clean.
- Everything streams to **`grid_viewer.py`** on the PC: occupied cells, planned path, goal, tracked pillars, and the virtual walls — so runs can be debugged visually.

> **Parking:** the same A\* + goal-cell mechanism drives the parallel-parking approach — the parking bay is simply a goal cell, with the surrounding geometry blocked so the planner threads the car in. (Parking-specific tuning is being finalized.)

### 6.7 Calibration note — two tuned configs
The Obstacle Challenge program is tuned as its **own configuration** and differs from the Open Challenge on a few constants. If you rebuild, use the values matching the program you run:

| Constant | `wro_open.py` | `grid_goto.py` |
|---|---|---|
| `COUNTS_PER_REV` | 205 | 165 |
| `WHEEL_D_MM` | 44.0 | 45.0 |
| `SERVO_MAX` | 60 | 50 |
| `GYRO_DIRECTION` | −1 | +1 |
| `MOTOR_IN1, IN2` | 23, 24 | 24, 23 |
| Camera | not used | Pi Camera (color) |

> ⚠️ These reflect re-calibration between build stages. Keep each script's header block as the source of truth for the config it was tuned with.

---

## 7. Reproducibility
- All source: [`/src`](../src) with a [README](../src/README.md) explaining each file
- Calibrated constants are defined at the top of each script and in [`other/pinout.md`](../other/pinout.md)
- Dependencies (Pi): `adafruit-circuitpython-mpu6050`, `rplidar-roboticia`, `gpiozero`, `pigpio` (built from source, `pigpiod` running)
- Dependencies (PC viewers): `numpy`, `matplotlib`, `pyvista`

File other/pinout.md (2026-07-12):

Full pinout & power reference
====

## Power
```
9V pack 1 --switch--> DRV8833 VM   (motor)
9V pack 2 --> XL4015 (5.0V) --> Servo VCC
2S 18650 (7.4V) --> buck (5.1V) --> USB-C --> Pi
LiDAR: single USB cable to Pi (power + data, /dev/ttyUSB0 @ 115200)
All GND --> star point --> one wire --> Pi pin 9
```

## GPIO
```
Pin 1  3.3V    Encoder VCC + MPU6050 VCC
Pin 3  GPIO2   MPU6050 SDA
Pin 5  GPIO3   MPU6050 SCL
Pin 9  GND     star ground reference
Pin 11 GPIO17  Encoder A
Pin 12 GPIO18  Servo signal
Pin 13 GPIO27  Encoder B
Pin 16 GPIO23  DRV8833 IN1
Pin 18 GPIO24  DRV8833 IN2
```

## Calibrated constants
```
Encoder: 205 counts/rev, MM_PER_COUNT = 0.674 (44 mm wheel), ENCODER_DIRECTION = -1
Gyro:    GYRO_DIRECTION = -1, deadzone 0.15 deg/s, calibrate at start line after warm-up
Servo:   SERVO_DIRECTION = +1 (positive = left), range ±60°
LiDAR:   mounted 180° rotated. Robot frame windows:
         front 170-190°, left 80-100°, right 260-280°, back 350-360°+0-10°
```

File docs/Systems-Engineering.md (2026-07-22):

# 🧠 Systems Thinking & Engineering Decisions

> **Rubric criterion 4 — Systems Thinking & Engineering Decisions.** This document shows *how the subsystems work together*, the constraints and trade-offs behind each major decision, the iteration cycles, and the risk analysis. Where the other docs answer "what" and "how," this one answers **"why we chose X instead of Y."**

---

## 1. The system as a whole

The vehicle is four subsystems that only work because of how they hand data to each other:

```mermaid
flowchart LR
    subgraph SENSE
    G[Gyro / MPU6050] -->|yaw rate| P
    E[Encoder] -->|distance| P
    L[LiDAR A1M8] -->|walls F/L/R| C
    end
    P[Pose estimator\nx, y, heading] --> C[Control\nstate machine + PID]
    C -->|servo angle| S[Steering servo]
    C -->|duty| M[Drive motor]
    P --> T[Telemetry / UDP]
    L --> T
    T --> V[PC live map + HUD]
```

**Interaction that matters most:** heading is owned by the gyro, distance by the encoder, and lane position/corner timing by the LiDAR — three *independent* information sources. If they were entangled (e.g. using LiDAR for heading too), one bad sensor could corrupt everything. Keeping them separate makes each failure local and diagnosable.

---

## 2. Key decisions: "why X instead of Y"

| Decision | We chose… | Instead of… | Why (data / reasoning) |
|---|---|---|---|
| Heading source | **Gyro integration** | LiDAR wall-angle estimation | Gyro gives a smooth, high-rate heading independent of wall geometry; LiDAR angle is noisy near corners. Trade-off accepted: gyro drifts, so we re-calibrate at the start line. |
| Steering | **Servo Ackermann** | Differential/skid steer | Predictable turn radius, decouples drive from steering, simpler control. |
| Power | **3 isolated sources + star ground** | Single shared battery | Shared battery caused Pi brownouts and I²C errors under motor load. Isolation fixed it. |
| Servo PWM | **Hardware PWM (pigpio)** | Software PWM | Software PWM jittered the steering; hardware PWM is rock-steady. |
| LiDAR orientation | **Remap angles in code** | Re-machine the mount | Cheaper, faster, zero mechanical risk — a software `LIDAR_MOUNT_OFFSET`. |
| Corner trigger | **Front distance + 3-scan confirm** | Single-scan threshold | Debounces false triggers from one noisy scan. |
| Start-from-rest | **Kick pulse in software** | Bigger/geared motor | Solves stall without adding weight or cost; kept as a safety margin. |
| Motor speed | **Slow to 55% in turns** | Constant speed | Constant speed caused understeer and inconsistent turn radius. |

---

## 3. Constraints we designed around

| Constraint | Impact on design |
|---|---|
| **Gyro drifts (~1°/3 s, thermal)** | Warm-up + start-line recalibration; deadzone to reject noise |
| **LiDAR needs clear 360° sweep** | LiDAR mounted at the highest point on a two-deck chassis |
| **Motor/servo current is noisy** | Isolated power rails, star ground, servo return off the Pi ground |
| **Pi is brownout-sensitive** | Dedicated 2S Li-ion + buck to 5.1 V just for the Pi |
| **WRO randomizes turn direction** | Direction auto-detected at the first corner, not hard-coded |
| **Standstill torque limited** | Kick-pulse launch; low-friction drivetrain |
| **Small arena, tight corners** | Slow-in/steady-out turn profile with full-lock steering |

---

## 4. Iteration cycles

Each version was a full **design → build → test → learn** loop. Details and photos in the [engineering journal](../engineering-journal).

| Version | Problem found | Change made | Result |
|---|---|---|---|
| **V1** | Baseline car ran but wandered and stalled | Established platform, first PID | Drives, but not centered or reliable |
| **V2** | LiDAR caught its own chassis; brownouts | Raised LiDAR to top deck; split power rails | Clean scans, no more Pi resets |
| **V3** | Steering jitter; motor stall from rest | Hardware PWM servo; kick pulse | Steady steering, reliable launch |
| **Final** | Heading drift into straights; wind-up | Start-line recalibration; reset integral on turn exit; centering smoothing | Repeatable 3-lap runs |

---

## 5. Risk analysis & mitigation

| Risk | Likelihood | Effect | Mitigation |
|---|---|---|---|
| Gyro drift accumulates over 3 laps | Medium | Heading target wrong → clips walls | Warm-up + recalibrate at start; low deadzone |
| Single bad LiDAR scan triggers false turn | Medium | Turns early → crash | 3-scan confirm + blind windows after start/turn |
| Motor fails to launch from rest | Low | DNF at start | Kick pulse; low-friction drivetrain verified |
| Pi brownout under motor stall | Was high → now low | Reboot mid-run → DNF | Isolated Pi power rail |
| PID wind-up after a corner | Medium | Overshoot into next straight | Clamp + reset integral on turn exit |
| Wi-Fi/telemetry drop | Low | Lose live map (not control) | Telemetry is best-effort; control loop never blocks on network |
| LiDAR stale-stream on reconnect | Low | No range data | `stop()`+`reset()` at startup |

**Failure-point philosophy:** telemetry, mapping, and the PC viewers are all *non-critical* — the car drives fully autonomously with zero network. This was a deliberate decision so a Wi-Fi issue at the venue can never cause a DNF.

---

## 6. What we would do next
- Fuse LiDAR into a light SLAM correction to bound gyro drift over long runs.
- Add the Obstacle Challenge vision pipeline (see [Software Architecture](./Software-Architecture.md)).
- Log runs to disk for offline tuning instead of live-only telemetry.

---

## 7. Reproducibility
Every decision above is traceable to code constants ([`src/`](../src)), the pinout ([`other/pinout.md`](../other/pinout.md)), the test log ([`other/test-procedure.md`](../other/test-procedure.md)), and the versioned [engineering journal](../engineering-journal).

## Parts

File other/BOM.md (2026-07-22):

# 🧾 Bill of Materials

All components used to build the vehicle. Quantities are per vehicle. Fill the **Qty / Notes / Source** columns with your actual purchase details before submission.

## Compute & sensing

| # | Component | Exact part | Qty | Interface | Notes |
|---|---|---|---|---|---|
| 1 | Single-board computer | **Raspberry Pi 4 Model B** | 1 | — | runs all flight code |
| 2 | 2D LiDAR | **Slamtec RPLidar A1M8** | 1 | USB `/dev/ttyUSB0` @115200 | 360° sweep; mounted 180° rotated |
| 3 | IMU | **MPU6050 (GY-521 board)** | 1 | I²C (GPIO2/3) | Z-gyro = heading source |
| 4 | Motor w/ encoder | **VT-E-G25A-06-177E** 25 mm DC gearmotor + quadrature encoder | 1 | GPIO17/27 (enc) | odometry — 205 c/rev (open) · 165 c/rev (obstacle) |
| 5 | Camera | **5 MP 175° fisheye CSI camera** (OV5647, 1.7 mm lens, 1/2.5") | 1 | CSI ribbon | Obstacle Challenge: red/green sign color |

## Actuation

| # | Component | Exact part | Qty | Interface | Notes |
|---|---|---|---|---|---|
| 6 | Motor driver | **DRV8833 dual H-bridge** | 1 | GPIO23/24 | drives the gearmotor (item 4); VM from 9 V rail |
| 7 | Steering servo | **MG996R** metal-gear servo | 1 | GPIO18 (hardware PWM) | Ackermann linkage; range ±60° (open) / ±50° (obstacle) |

## Power

| # | Component | Exact part | Qty | Feeds | Notes |
|---|---|---|---|---|---|
| 8 | 9 V Li-ion battery | **DAWEIKALA 9 V 6600 mAh USB-C rechargeable** | 1 | Drive motor (DRV8833 VM) | via power switch |
| 9 | 9 V Li-ion battery | **DAWEIKALA 9 V 6600 mAh USB-C rechargeable** | 1 | Servo (via XL4015 buck) | isolated from logic |
| 10 | Buck converter | **XL4015 5 A adjustable step-down** | 1 | Servo VCC → 5.0 V | — |
| 11 | 18650 Li-ion cells | **3.7 V 18650 (2S = 7.4 V pack)** | 2 | Pi (via buck) | dedicated logic supply |
| 12 | Buck converter | 5 V USB-C step-down | 1 | Raspberry Pi → 5.1 V | brownout-proof Pi rail |
| 13 | Power switch | rocker/slide switch | 1 | motor rail | main arm switch |

> Three isolated sources joined at one **star ground**. See [`other/pinout.md`](./pinout.md) and [`/schemes`](../schemes).

## Chassis & hardware

| # | Component | Spec | Qty | Notes |
|---|---|---|---|---|
| 14 | Chassis / body | 3D-printed (2-deck), scale-car shell | 1 set | see [`/models`](../models) CAD/STL |
| 15 | Standoffs | metal | 4 | join decks rigidly |
| 16 | Wheels | rubber, ~44 mm dia | 4 | rear driven · front steered |
| 17 | Wiring, connectors, star-ground point | — | — | see [`/schemes`](../schemes) |

## Component photos

| | | |
|:---:|:---:|:---:|
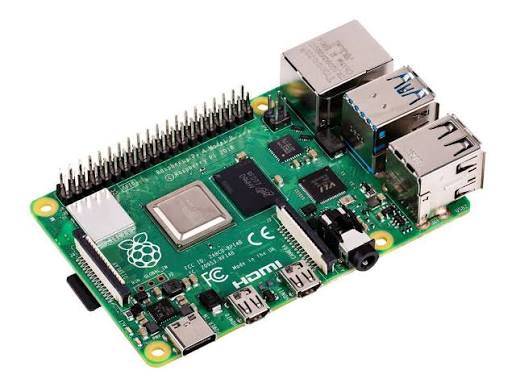
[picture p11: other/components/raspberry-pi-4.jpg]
Pi 4
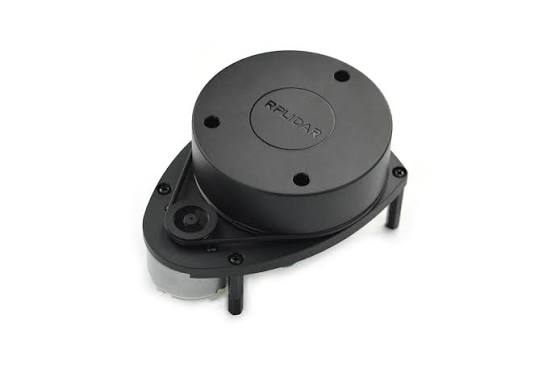
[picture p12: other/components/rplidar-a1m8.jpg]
RPLidar
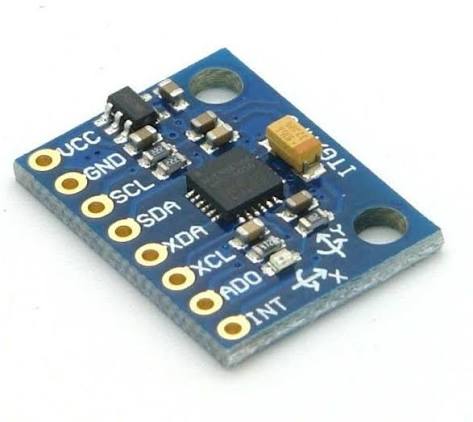
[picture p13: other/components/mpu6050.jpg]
MPU6050
| <br>**Raspberry Pi 4** | <br>**RPLidar A1M8** | <br>**MPU6050 (GY-521)** |
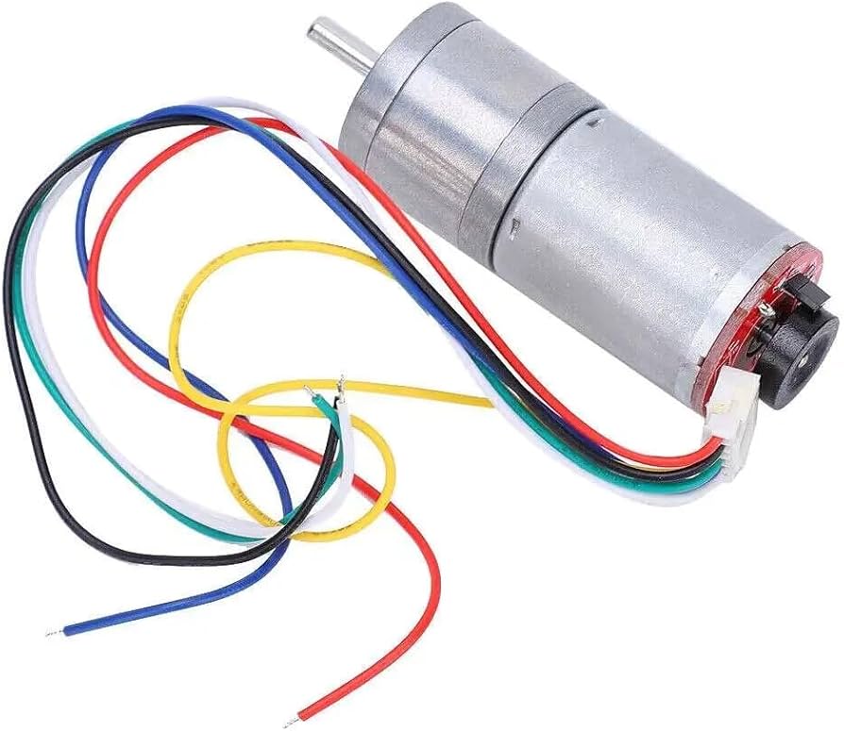
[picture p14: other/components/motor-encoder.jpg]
Motor
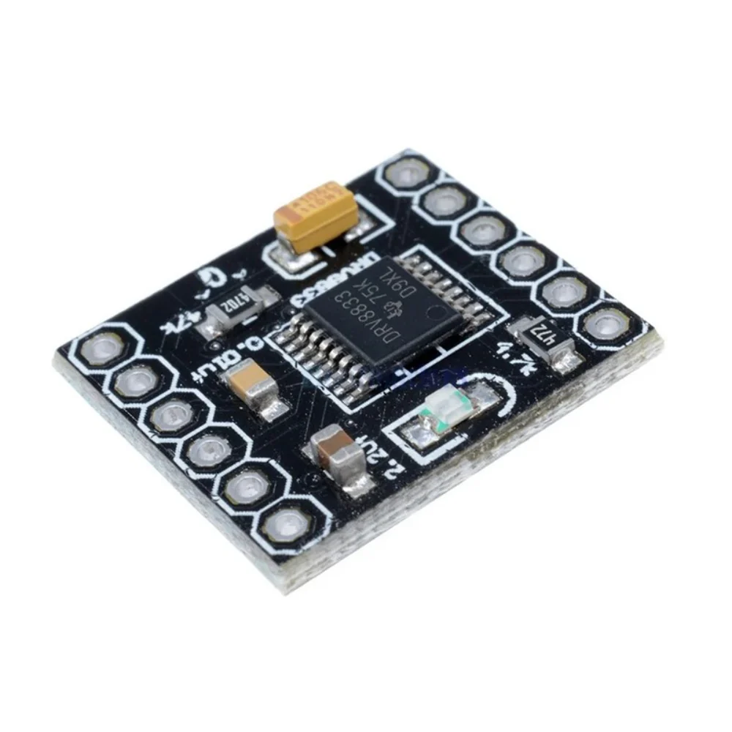
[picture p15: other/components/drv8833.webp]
DRV8833
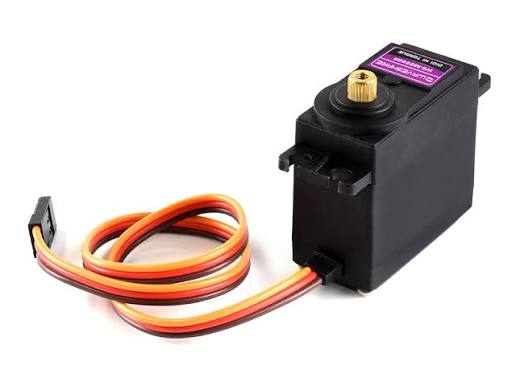
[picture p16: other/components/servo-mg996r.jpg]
Servo
| <br>**Gearmotor + encoder** | <br>**DRV8833 driver** | <br>**MG996R servo** |
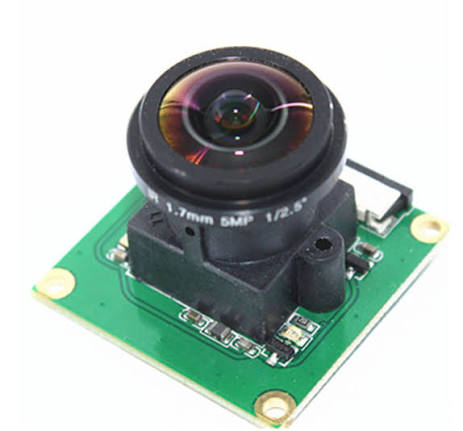
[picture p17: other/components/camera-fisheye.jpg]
Camera
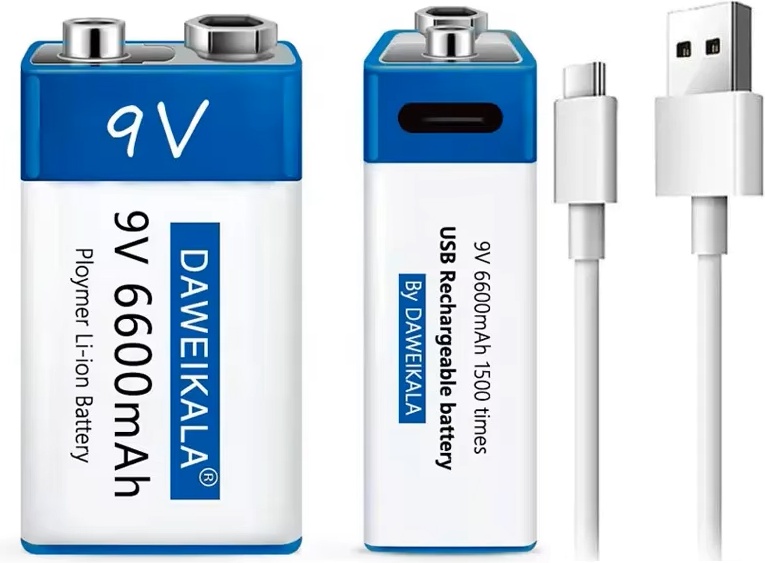
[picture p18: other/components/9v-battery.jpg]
9V
| <br>**Fisheye CSI camera** | <br>**9V USB-C Li-ion** | XL4015<br>**XL4015 buck** |
| <br>**18650 cell (2S)** | | |

## Software / firmware

| Item | Where |
|---|---|
| Flight & viewer code | [`/src`](../src) |
| Pinout & calibrated constants | [`other/pinout.md`](./pinout.md) |
| Wiring diagram | [`/schemes`](../schemes) |

> 💡 Reproducibility tip: pair this BOM with the calibrated constants in [`pinout.md`](./pinout.md) and the CAD in [`/models`](../models) so another team can rebuild the vehicle exactly.

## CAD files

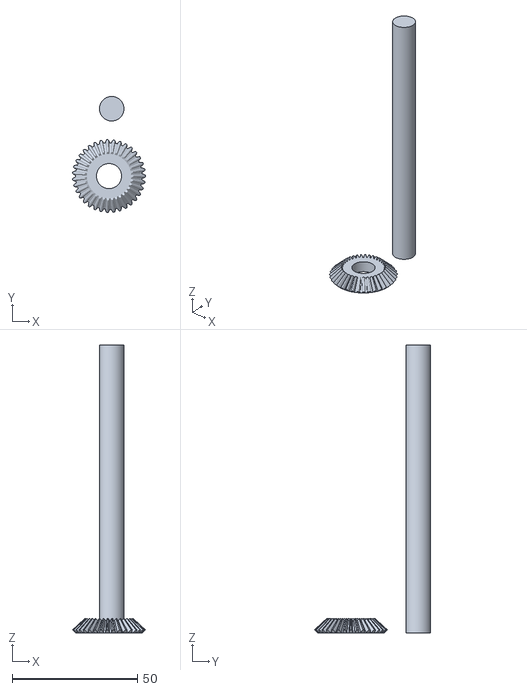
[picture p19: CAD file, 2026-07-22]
models/STL/MotorShaft.stl
29.1 x 46.4 x 115.0

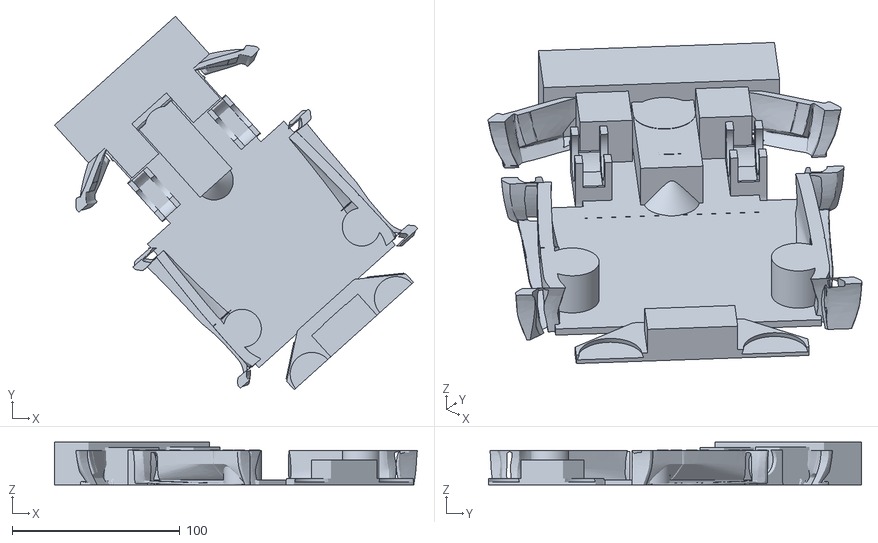
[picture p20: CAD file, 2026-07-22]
models/STL/CarBottom.stl
216.2 x 222.4 x 25.6

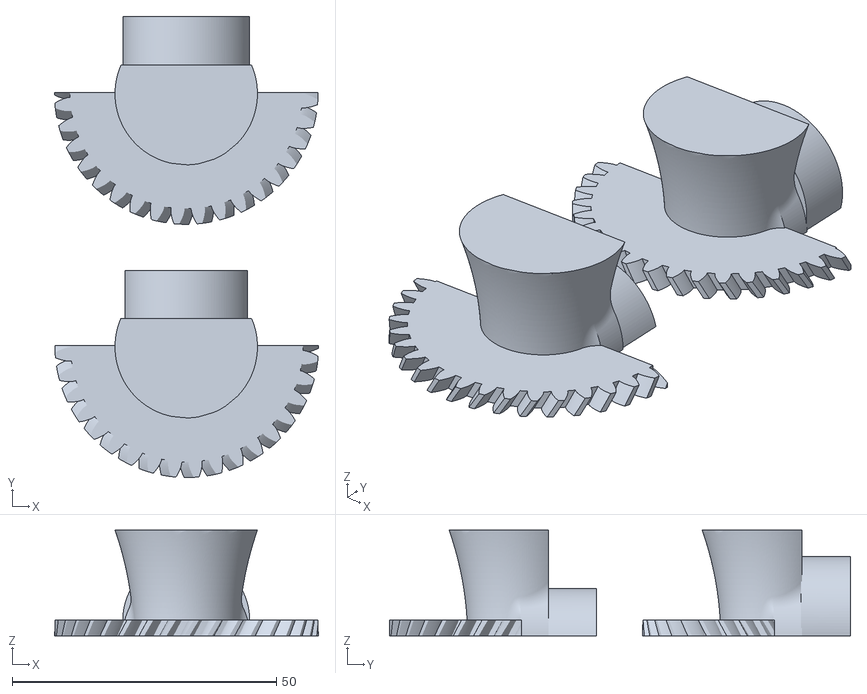
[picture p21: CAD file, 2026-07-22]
models/STL/Steering.stl
50.0 x 87.2 x 20.0

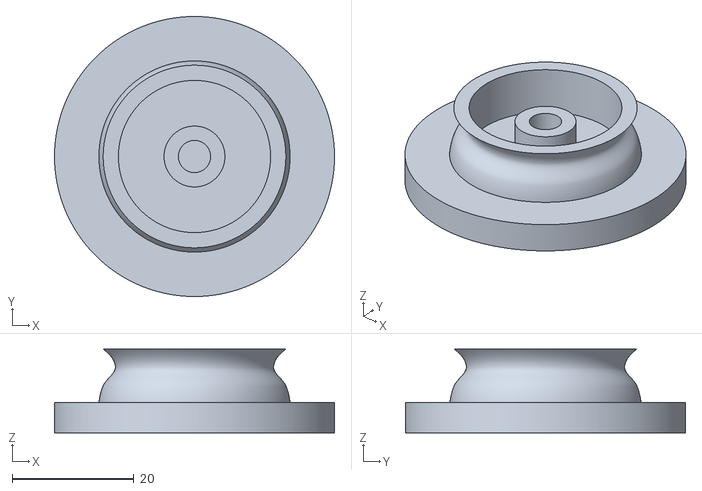
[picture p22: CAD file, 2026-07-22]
models/STL/Wheels.stl
46.0 x 46.0 x 13.8

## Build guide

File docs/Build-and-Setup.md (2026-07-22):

# 🛠️ Build & Setup Guide

How to rebuild and run the vehicle from scratch. Pair this with the [BOM](../other/BOM.md), the [wiring diagram](../schemes), and the [pinout](../other/pinout.md).

---

## 1. Assemble the hardware

1. **Build the two-deck chassis** from the CAD/STL in [`/models`](../models); join the decks with 4 standoffs. See [Mechanical Design](./Mechanical-Design.md).
2. **Lower deck:** mount the drive motor + encoder, DRV8833, steering servo + Ackermann linkage, and the battery packs (keep them low).
3. **Upper deck:** mount the Raspberry Pi, MPU6050 (near the yaw axis), and the RPLidar at the highest point for a clear 360° sweep.
4. **Wire per** [`other/pinout.md`](../other/pinout.md) and [`/schemes`](../schemes). Critically: **three isolated power sources, one star ground**; route the servo return to its own converter ground, not the Pi.

---

## 2. Prepare the Raspberry Pi

```bash
# OS: Raspberry Pi OS (Debian). Enable I2C:
sudo raspi-config          # Interface Options -> I2C -> enable

# System deps
sudo apt update
sudo apt install -y python3-pip git

# pigpio built from source (needed for jitter-free hardware PWM)
# then run the daemon:
sudo pigpiod

# Python libraries
pip3 install adafruit-circuitpython-mpu6050 rplidar-roboticia gpiozero
```

Grant serial access to the LiDAR (`/dev/ttyUSB0`) if needed:
```bash
sudo usermod -a -G dialout $USER   # re-login after this
```

---

## 3. Prepare the PC (live map, optional)

The car drives fully autonomously without the PC. For live visualization:

```bash
pip install numpy matplotlib pyvista
```

Set the PC's IP in [`src/wro_open.py`](../src/wro_open.py) / [`src/robot_mapper.py`](../src/robot_mapper.py):
```python
PC_IP, PC_PORT = "192.168.1.42", 5005   # <-- your PC's LAN IP
```

---

## 4. Calibrate before every run

1. **Warm up** the electronics ~60 s (reduces gyro thermal drift).
2. Place the car at the **start line**, held still.
3. Launch the program — it **auto-calibrates the gyro** (300 samples) on startup.
4. Confirm the [component tests](../other/test-procedure.md) pass if anything was changed.

---

## 5. Run

**Open Challenge (autonomous, on the Pi):**
```bash
python3 src/wro_open.py
# press ENTER to arm; CTRL+C to stop
```

**Live map (optional, on the PC — start FIRST):**
```bash
python3 src/map_viewer_pro.py     # full telemetry HUD + 2.5D map
# then start wro_open.py or robot_mapper.py on the Pi
```

**Mapping test only (no driving logic):**
```bash
python3 src/robot_mapper.py       # push or drive; map builds either way
```

---

## 6. Troubleshooting

| Symptom | Likely cause | Fix |
|---|---|---|
| Servo jitters | software PWM | ensure `pigpiod` is running; use GPIO18 hardware PWM |
| Pi reboots under load | shared/weak power | verify isolated Pi rail + star ground |
| Heading drifts | cold gyro | warm up + recalibrate at start line |
| LiDAR errors on start | stale stream | `stop()`+`reset()` already in code; re-seat USB |
| Car turns early/late | corner threshold | tune `TURN_TRIGGER_DIST` / `TURN_CONFIRM` |
| Car hugs one wall | centering sign | flip sign of `CENTER_GAIN` |

See the [Software Architecture](./Software-Architecture.md) doc for what every constant does.

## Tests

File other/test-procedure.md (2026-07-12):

Component test procedure
====

Each module was validated in isolation before integration (scripts in `src/tests/`):

1. **Servo** — sweep test; jitter eliminated with pigpio hardware PWM (built from source on Debian 13).
2. **Gyro** (`test_gyro.py`) — heading integration; verified 90°/360° physical rotations; ~1°/3s drift traced to thermal bias → re-calibrate at start line after 60 s warm-up.
3. **Motor** (`test_motor.py`) — direction + ramp test; standstill torque solved mechanically; software kick-pulse retained as safety.
4. **Encoder** (`test_encoder.py`, `test_distance.py`) — counts/rev measured experimentally (205); verified with a 50 cm tape-measure push reading 500 mm.
5. **LiDAR** (`test_lidar_pi.py`) — four-direction wall distances; startup `stop()+reset()` added after discovering stale-stream descriptor errors; direction windows remapped for the 180° mount.
6. **Turning** (`test_turn.py`) — gyro-closed-loop turns to absolute headings with P-controlled steering release.
7. **Mapping** — pushed-lap test: walls form closed straight lines and the trail returns to origin, validating encoder+gyro dead reckoning before autonomous runs.

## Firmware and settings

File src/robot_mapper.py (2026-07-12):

"""
robot_mapper.py — runs on the RASPBERRY PI.

Tracks the robot pose (x, y, heading) using encoder + gyro,
transforms LiDAR points into world coordinates, and streams
pose + points over UDP to the PC for live visualization.

Push the robot by hand or drive it — the map builds either way.

Companion file: map_viewer.py (runs on the PC).
"""

import adafruit_mpu6050
import board
import time
import threading
import math
import json
import socket

from gpiozero import RotaryEncoder
from rplidar import RPLidar

# =============================
# Network
# =============================

PC_IP   = "192.168.1.42"
PC_PORT = 5005

sock = socket.socket(socket.AF_INET, socket.SOCK_DGRAM)

# =============================
# Encoder (calibrated values)
# =============================

ENCODER_A         = 17
ENCODER_B         = 27
ENCODER_DIRECTION = -1
COUNTS_PER_REV    = 205
WHEEL_DIAMETER_MM = 44.0
MM_PER_COUNT      = (math.pi * WHEEL_DIAMETER_MM) / COUNTS_PER_REV

# =============================
# Gyro
# =============================

GYRO_DIRECTION = -1
GYRO_DEADZONE  = 0.5   # deg/s

# =============================
# LiDAR (robot frame: mounted 180 deg rotated)
# =============================

LIDAR_PORT     = "/dev/ttyUSB0"
LIDAR_BAUDRATE = 115200
MAX_DIST       = 3000   # mm

# LiDAR 0 deg faces robot REAR. To convert a LiDAR angle to the
# robot frame (0 = robot front, CCW positive), we use:
#   robot_angle = 180 - lidar_angle   (then heading is added later)
LIDAR_MOUNT_OFFSET = 180.0

# =============================
# Hardware setup
# =============================

print("Initializing MPU6050...")
i2c = board.I2C()
mpu = adafruit_mpu6050.MPU6050(i2c)

def calibrate_gyro(samples=300):
    print("Calibrating gyro — keep robot still...")
    total = 0.0
    for _ in range(samples):
        total += mpu.gyro[2]
        time.sleep(0.005)
    offset = total / samples
    print(f"Gyro offset: {offset:.6f} rad/s")
    return offset

gyro_offset = calibrate_gyro()

print("Initializing encoder...")
encoder = RotaryEncoder(ENCODER_A, ENCODER_B, max_steps=10000000)
encoder.steps = 0

print(f"Connecting to LiDAR on {LIDAR_PORT}...")
lidar = RPLidar(LIDAR_PORT, baudrate=LIDAR_BAUDRATE)
lidar.stop()
lidar.reset()
time.sleep(0.5)

# =============================
# LiDAR background thread
# =============================

latest_scan = []
scan_lock   = threading.Lock()
running     = [True]

def scan_thread():
    for scan in lidar.iter_scans(max_buf_meas=500):
        if not running[0]:
            break
        with scan_lock:
            latest_scan.clear()
            latest_scan.extend(scan)

t = threading.Thread(target=scan_thread, daemon=True)
t.start()

# =============================
# Pose state
# =============================

x_mm      = 0.0
y_mm      = 0.0
heading   = 0.0     # degrees, 0 = initial facing, CCW positive
last_time = time.time()
last_counts = 0

def update_pose():
    """Dead reckoning: gyro for heading, encoder for distance."""
    global x_mm, y_mm, heading, last_time, last_counts

    now = time.time()
    dt  = now - last_time
    last_time = now

    # Heading from gyro
    gz = (mpu.gyro[2] - gyro_offset) * (180.0 / math.pi)
    if abs(gz) < GYRO_DEADZONE:
        gz = 0.0
    gz *= GYRO_DIRECTION
    heading += gz * dt

    # Distance from encoder since last frame
    counts       = encoder.steps * ENCODER_DIRECTION
    delta_counts = counts - last_counts
    last_counts  = counts
    delta_mm     = delta_counts * MM_PER_COUNT

    # Advance position along current heading
    h_rad = math.radians(heading)
    x_mm += delta_mm * math.cos(h_rad)
    y_mm += delta_mm * math.sin(h_rad)

def scan_to_world():
    """Transform current LiDAR scan into world-frame points."""
    with scan_lock:
        scan = list(latest_scan)

    points = []
    h = heading
    for quality, angle, distance in scan:
        if quality > 0 and 0 < distance <= MAX_DIST:
            # LiDAR angle -> robot frame -> world frame
            world_angle = math.radians(LIDAR_MOUNT_OFFSET - angle + h)
            px = x_mm + distance * math.cos(world_angle)
            py = y_mm + distance * math.sin(world_angle)
            # Round to save bandwidth
            points.append((round(px), round(py)))
    return points

# =============================
# Main loop
# =============================

print(f"""
========================================
ROBOT MAPPER — streaming to {PC_IP}:{PC_PORT}
========================================
Start map_viewer.py on the PC, then move
the robot (push or drive).
Press CTRL+C to stop.
========================================
""")

SEND_INTERVAL = 0.1   # seconds between packets (10 Hz)
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

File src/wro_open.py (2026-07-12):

"""
wro_open.py — WRO Open Challenge navigation. Runs on the Pi.

Architecture:
  GYRO    -> heading hold (PID) + executes 90 deg turns (full-lock profile)
  LIDAR   -> left/right centering trim + front-wall corner trigger
  ENCODER -> odometry for the live map
  UDP     -> streams pose/scan/state to map_viewer.py / map_viewer_3d.py

State machine:
  STRAIGHT -> gyro holds snapped target (0/90/180/270...), LiDAR trims it
  TURNING  -> full-lock steering until near target, then steep ramp
  FINISHED -> after 3 laps (1080 deg cumulative)

Turn direction DETECTED at first corner (WRO randomizes it).
Startup is ARMED after ENTER: state zeroed + 1 s corner-blind window.
"""

import adafruit_mpu6050
import board
import time
import threading
import math
import json
import socket

from gpiozero import AngularServo, PWMOutputDevice, RotaryEncoder
from gpiozero.pins.pigpio import PiGPIOFactory
from rplidar import RPLidar

# ============================================================
# CONFIG
# ============================================================

# ---- Network (live map) ----
PC_IP, PC_PORT = "192.168.1.42", 5005
SEND_EVERY_N_LOOPS = 3

# ---- Pins ----
SERVO_PIN = 18
MOTOR_IN1, MOTOR_IN2 = 23, 24
ENCODER_A, ENCODER_B = 17, 27

# ---- Motor ----
SPEED_STRAIGHT = 0.8
SPEED_TURN     = 0.55
KICK_SPEED     = 1.0
KICK_TIME      = 0.15

# ---- Servo ----
SERVO_MAX       = 60
SERVO_DIRECTION = 1        # positive = steer LEFT

# ---- Turn steering profile ----
TURN_FULL_LOCK   = 55      # servo angle held during the turn
TURN_RELEASE_DEG = 25      # ease off only when this close to target

# ---- Gyro ----
GYRO_DIRECTION = -1
GYRO_DEADZONE  = 0.05      # deg/s (low: don't eat slow veers)

# ---- Steering PID (heading hold on straights) ----
KP, KI, KD = 0.9, 0.05, 0.15
KD_FILTER  = 0.3
I_CLAMP    = 30

# ---- LiDAR ----
LIDAR_PORT, LIDAR_BAUD = "/dev/ttyUSB0", 115200
MAX_DIST = 3000
WIN_FRONT = [(170, 190)]     # robot frame; LiDAR mounted 180 deg rotated
WIN_LEFT  = [(80, 100)]
WIN_RIGHT = [(260, 280)]

# ---- Centering ----
CENTER_GAIN     = 0.010    # deg trim per mm of (left-right); flip sign if diverging
CENTER_TRIM_MAX = 6.0
CENTER_DEADZONE = 30       # mm
CENTER_SMOOTH_N = 4

# ---- Corner logic ----
TURN_TRIGGER_DIST = 600    # mm
TURN_CONFIRM      = 3      # consecutive scans
TURN_EXIT_TOL     = 4.0    # deg
OPEN_SIDE_MIN     = 900    # mm; side larger than this = open corridor
POST_TURN_BLIND   = 0.4    # s
START_BLIND       = 1.0    # s after ENTER with no corner triggers

# ---- Mission ----
LAP_LIMIT     = 1080.0
LAP_TOLERANCE = 15.0

# ---- Encoder (calibrated) ----
ENCODER_DIRECTION = -1
COUNTS_PER_REV    = 205
WHEEL_D_MM        = 44.0
MM_PER_COUNT      = math.pi * WHEEL_D_MM / COUNTS_PER_REV

# ============================================================
# HARDWARE SETUP
# ============================================================

print("pigpio servo factory...")
factory = PiGPIOFactory()

print("Servo...")
servo = AngularServo(SERVO_PIN, min_angle=-SERVO_MAX, max_angle=SERVO_MAX,
                     min_pulse_width=0.0005, max_pulse_width=0.0025,
                     pin_factory=factory)
servo.angle = 0

print("Motor...")
m1 = PWMOutputDevice(MOTOR_IN1, pin_factory=factory)
m2 = PWMOutputDevice(MOTOR_IN2, pin_factory=factory)

print("Encoder...")
encoder = RotaryEncoder(ENCODER_A, ENCODER_B, max_steps=10000000,
                        pin_factory=factory)
encoder.steps = 0

print("MPU6050...")
i2c = board.I2C()
mpu = adafruit_mpu6050.MPU6050(i2c)

def calibrate_gyro(n=300):
    print("Calibrating gyro — keep robot STILL...")
    s = 0.0
    for _ in range(n):
        s += mpu.gyro[2]
        time.sleep(0.005)
    off = s / n
    print(f"  offset {off:.6f} rad/s")
    return off

gyro_offset = calibrate_gyro()

print("LiDAR...")
lidar = RPLidar(LIDAR_PORT, baudrate=LIDAR_BAUD)
lidar.stop(); lidar.reset(); time.sleep(0.5)

latest_scan, scan_lock, running = [], threading.Lock(), [True]
def scan_thread():
    for scan in lidar.iter_scans(max_buf_meas=500):
        if not running[0]:
            break
        with scan_lock:
            latest_scan.clear()
            latest_scan.extend(scan)
threading.Thread(target=scan_thread, daemon=True).start()

sock = socket.socket(socket.AF_INET, socket.SOCK_DGRAM)

# ============================================================
# HELPERS
# ============================================================

def clamp(v, lo, hi):
    return max(lo, min(hi, v))

_motor_moving = False
current_speed = 0.0        # what we COMMAND the motor right now (0..1)

def motor(speed):
    """Forward drive with a kick pulse when starting from rest."""
    global _motor_moving, current_speed
    current_speed = clamp(speed, 0.0, 1.0)
    if current_speed <= 0:
        m1.value = 0.0; m2.value = 0.0
        _motor_moving = False
        return
    if not _motor_moving:
        m1.value = KICK_SPEED; m2.value = 0.0
        time.sleep(KICK_TIME)
        _motor_moving = True
    m1.value = current_speed; m2.value = 0.0

def lidar_min(scan, windows):
    d = [dist for q, a, dist in scan
         if q > 0 and 0 < dist <= MAX_DIST
         and any(lo <= a <= hi for lo, hi in windows)]
    return min(d) if d else None

# ============================================================
# STATE
# ============================================================

heading     = 0.0
last_t      = time.time()
x_mm = y_mm = 0.0
last_counts = 0

target       = 0.0
snapped      = 0.0
turn_dir     = 0
state        = "STRAIGHT"
corner_count = 0
confirm      = 0
blind_until  = 0.0

integ = 0.0
last_err = 0.0
fderiv = 0.0
center_hist = []

def update_pose():
    global heading, last_t, x_mm, y_mm, last_counts
    now = time.time(); dt = now - last_t; last_t = now
    gz = (mpu.gyro[2] - gyro_offset) * (180.0 / math.pi)
    if abs(gz) < GYRO_DEADZONE: gz = 0.0
    heading += gz * GYRO_DIRECTION * dt

    c = encoder.steps * ENCODER_DIRECTION
    d_mm = (c - last_counts) * MM_PER_COUNT
    last_counts = c
    h = math.radians(heading)
    x_mm += d_mm * math.cos(h)
    y_mm += d_mm * math.sin(h)

def pid_steer():
    global integ, last_err, fderiv
    err = target - heading
    integ = clamp(integ + err, -I_CLAMP, I_CLAMP)
    raw_d = err - last_err
    fderiv = (1 - KD_FILTER) * raw_d + KD_FILTER * fderiv
    last_err = err
    out = (KP * err + KI * integ + KD * fderiv) * SERVO_DIRECTION
    return clamp(out, -SERVO_MAX, SERVO_MAX)

def turn_steer():
    """Full lock until TURN_RELEASE_DEG from target, then steep ramp."""
    err = target - heading
    if abs(err) > TURN_RELEASE_DEG:
        steer = TURN_FULL_LOCK * (1 if err > 0 else -1)
    else:
        steer = (TURN_FULL_LOCK / TURN_RELEASE_DEG) * err
    return clamp(steer * SERVO_DIRECTION, -SERVO_MAX, SERVO_MAX)

def smoothed_center_error(left, right):
    center_hist.append(left - right)
    if len(center_hist) > CENTER_SMOOTH_N:
        center_hist.pop(0)
    return sum(center_hist) / len(center_hist)
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

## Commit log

2026-07-22 Add photos, wiring diagrams, and A* path visualization
2026-07-22 Fill WRO 2026 documentation, code, media; remove placeholders
    [CarBottom.stl, MotorShaft.stl, Steering.stl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]
